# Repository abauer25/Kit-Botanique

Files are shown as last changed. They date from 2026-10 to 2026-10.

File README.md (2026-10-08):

# Kit Botanique V2

<p align="center">
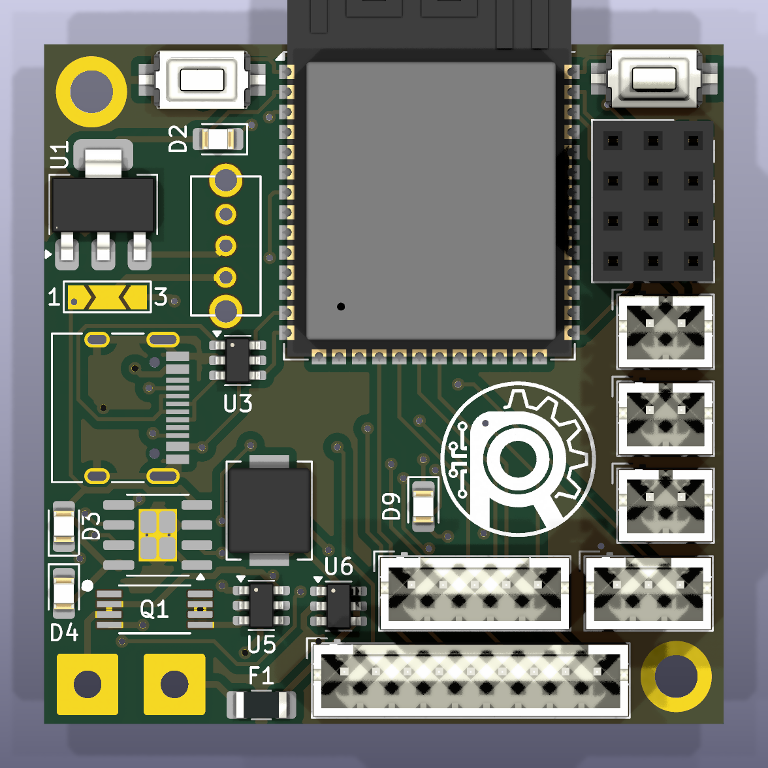
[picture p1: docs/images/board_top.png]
Top side of the board
  
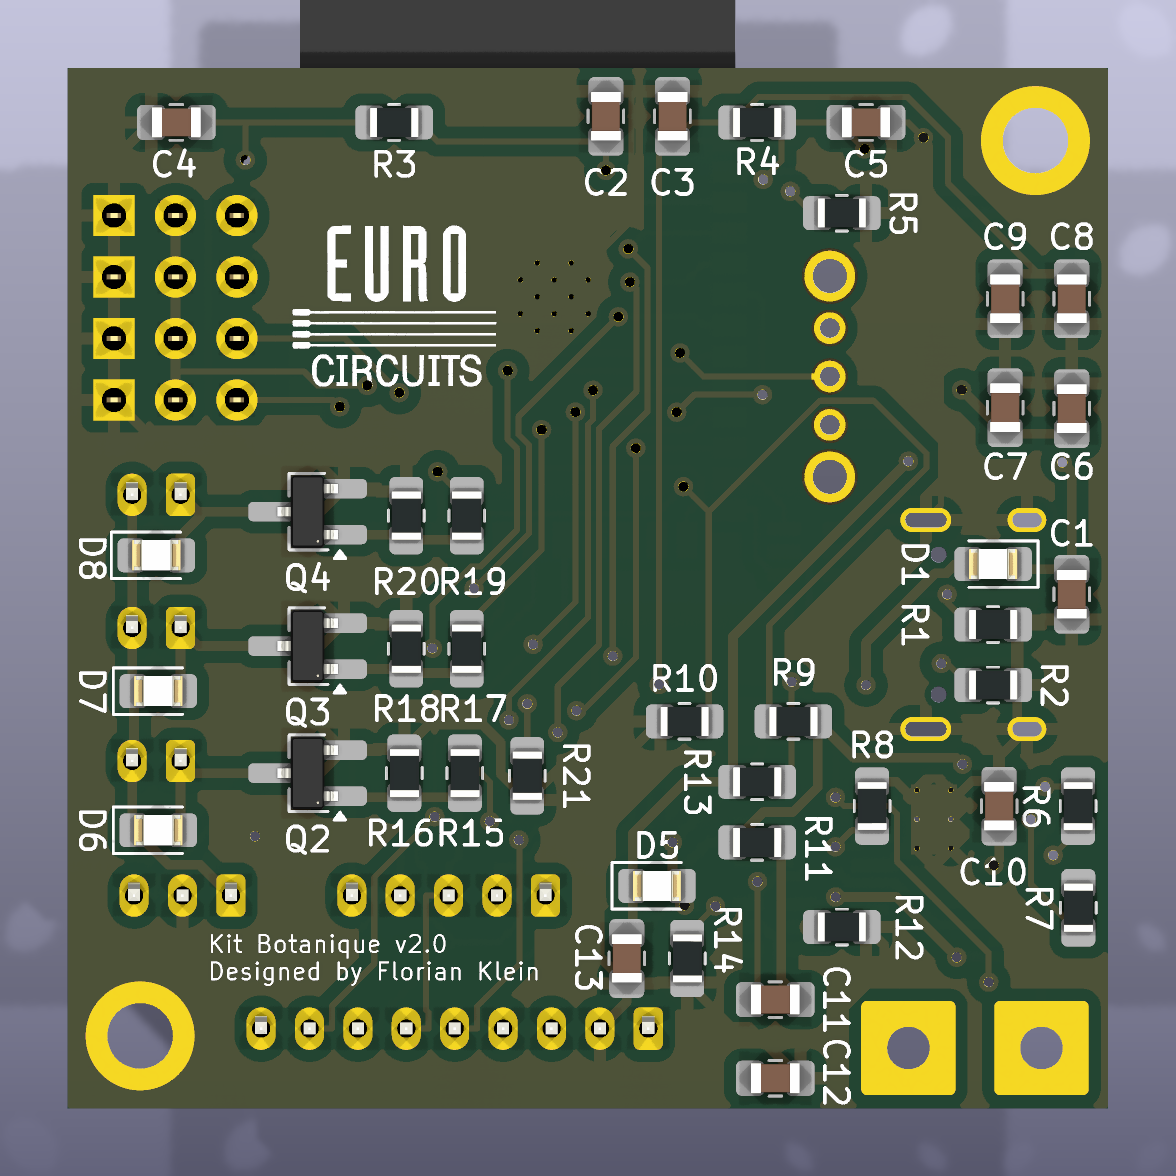
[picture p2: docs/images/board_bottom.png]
Bottom side of the board
  
</p>

The Kit Botanique is an automatic plant watering kit designed by [Robopoly](https://www.epfl.ch/campus/associations/robopoly/), the student makerspace of EPFL. It measures soil moisture and switches small pumps on when the plants need water.

Robopoly members buy the kit as separate parts and solder it themselves at the workshop, with help from the committee. It is an advanced kit: it uses small surface-mount components, so soldering experience is recommended but not required.

## Features

- ESP32-S3 module (WiFi and Bluetooth), programmed over USB-C with the Arduino IDE
- 3 pump outputs and 4 sensor inputs (soil moisture or water level)
- Powered over USB-C, or by a Li-ion battery with the optional battery extension
- Connectors for an LED strip and a touchscreen
- 43 × 43 mm board

The basic kit contains the board, one peristaltic pump and one soil moisture sensor.

## Repository contents

| Folder | Content |
|---|---|
| [`docs/`](docs) | [Assembly guide](docs/assembly_guide_v2.pdf), [schematic](docs/schema_v2.pdf), images |
| [`firmware/tests/`](firmware/tests) | Test programs used during assembly |
| [`hardware/kicad/`](hardware/kicad) | KiCad 10 project (schematic, PCB, libraries) |
| [`hardware/fabrication/`](hardware/fabrication) | Gerber files and bill of materials |
| [`hardware/3d/`](hardware/3d) | 3D model of the assembled board (STEP) |
| [`archive/v1/`](archive/v1) | Code of the first version of the kit |

## Building the kit

Follow the [assembly guide](docs/assembly_guide_v2.pdf) (in French for now). It goes step by step, with a test after each stage. Do not move on until the test passes.

| Stage | Guide sections | Test |
|---|---|---|
| 1. Power supply and ESP32 module | 1 to 9 | The blue LED lights up |
| 2. Buttons and white LED | 10 and 11 | `01_blink` makes the white LED blink |
| 3. Pumps and sensors | 12 to 14 | `02_pump_sensor_test` reads the sensors and runs the pumps |
| 4. Battery extension (optional) | 15 to 18 | |
| 5. Screen and LED strip connectors (optional) | 19 | |

Two things to know before you start:

- **Both sides of the board are used.** All resistors, capacitors, the Schottky diodes and the pump transistors go on the **bottom** side. The chips, LEDs, buttons and connectors go on the **top** side. Check the pictures above.
- **The 3-pad solder jumper (marked 1 and 3) selects the power source.** Bridge pads 1 and 2 for USB power (basic kit). Bridge pads 2 and 3 for battery power (battery extension). Never bridge all three pads.

## Programming

1. Install the [Arduino IDE](https://www.arduino.cc/en/software), then the **esp32 by Espressif Systems** package from the Boards Manager.
2. In the **Tools** menu, use these settings:

   | Setting | Value |
   |---|---|
   | Board | ESP32S3 Dev Module |
   | USB CDC On Boot | **Enabled** (otherwise the Serial Monitor stays empty) |
   | USB Mode | Hardware CDC and JTAG |
   | Upload Mode | USB-OTG CDC (TinyUSB) |
   | Flash Size | 4MB (32Mb) |
   | Partition Scheme | Default 4MB with spiffs |
   | PSRAM | Disabled |

3. Put the board in download mode: hold **BOOT** (top right button), press and release **RESET** (top left button), then release BOOT.
4. Upload the sketch. Then switch the board off and on again to start it.

The test programs in [`firmware/tests/`](firmware/tests):

| Sketch | What it does |
|---|---|
| [`01_blink`](firmware/tests/01_blink/01_blink.ino) | Blinks the white LED once per second |
| [`02_pump_sensor_test`](firmware/tests/02_pump_sensor_test/02_pump_sensor_test.ino) | Prints the 4 sensor values on the Serial Monitor (115200 baud), then runs the 3 pumps for 3 seconds |

> **Careful:** the white LED and pump 1 use the same pin. `01_blink` also runs pump 1 if one is plugged in.

The watering program itself is not written yet.

## Pinout

| GPIO | Function |
|---|---|
| 1, 2, 3, 4 | Sensor inputs C1 to C4 |
| 17, 18, 21 | Pumps 1 to 3 (pump 1 shares GPIO 17 with the white LED) |
| 15 | LED strip data |
| 14 | Battery voltage divided by 2 |
| 5, 6, 7, 10 | Screen: RST, DC, backlight, CS |
| 8, 16 | Touchscreen: CS, IRQ |
| 11, 12, 13 | SPI shared by screen and touchscreen: MOSI, SCLK, MISO |
| 0 | BOOT button |

Sensors are powered with 5 V, but their signal goes straight to the ESP32 and must stay below 3.3 V.

The full wiring is in the [schematic](docs/schema_v2.pdf).

## Hardware files

The KiCad project is in [`hardware/kicad/`](hardware/kicad). Open `kit_botanique_v2.kicad_pro` with KiCad 10 or later. The board is manufactured by Eurocircuits from [`gerber_v2.zip`](hardware/fabrication/gerber_v2.zip), the files that were sent for the current boards.

## First version

The first Kit Botanique used an ESP32 development board with 6 pumps and 6 sensors. Its code is kept in [`archive/v1/`](archive/v1/Sensors_Pumps_Test/Sensors_Pumps_Test.ino).

## Links

- [Kit Botanique V2 page](https://www.epfl.ch/campus/associations/robopoly/kits/kit-botanique-v2/)
- [Robopoly](https://www.epfl.ch/campus/associations/robopoly/), workshop BM 9139, EPFL
- Contact: [robopoly@epfl.ch](mailto:robopoly@epfl.ch)

## License

This project is published by Robopoly under the [Creative Commons Attribution-NonCommercial-ShareAlike 4.0](LICENSE.txt) license.

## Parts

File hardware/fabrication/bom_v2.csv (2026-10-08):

Reference | Qty | Value | DNP | Exclude from BOM | Exclude from Board | Footprint | Datasheet | LCSC
C1,C2,C6,C8,C10 | 5 | 10uF |  |  |  | Capacitor_SMD:C_0805_2012Metric_Pad1.18x1.45mm_HandSolder | ~
C3,C4,C5,C7,C9,C11 | 6 | 100nF |  |  |  | Capacitor_SMD:C_0805_2012Metric_Pad1.18x1.45mm_HandSolder | ~
C12,C13 | 2 | 22uF |  |  |  | Capacitor_SMD:C_0805_2012Metric_Pad1.18x1.45mm_HandSolder | ~
D1,D5,D6,D7,D8 | 5 | 1N5819HW-7-F |  |  |  | LED_SMD:LED_0805_2012Metric_Pad1.15x1.40mm_HandSolder | https://datasheet.lcsc.com/lcsc/2204281430_Guangdong-Hottech-1N5819WS_C191023.pdf
D2,D3,D4,D9 | 4 | LED |  |  |  | LED_SMD:LED_0805_2012Metric_Pad1.15x1.40mm_HandSolder | ~
F1 | 1 | Polyfuse |  |  |  | Fuse:Fuse_1206_3216Metric_Pad1.42x1.75mm_HandSolder | ~
J1 | 1 | USB_C_Receptacle_USB2.0_16P |  |  |  | Connector_USB:USB_C_Receptacle_HRO_TYPE-C-31-M-12 | https://www.usb.org/sites/default/files/documents/usb_type-c.zip | C165948
J2 | 1 | Screen |  |  |  | Connector_JST:JST_PH_B9B-PH-K_1x09_P2.00mm_Vertical | ~
J3 | 1 | C1 |  |  |  | Connector_PinSocket_2.54mm:PinSocket_1x03_P2.54mm_Vertical | ~
J4 | 1 | touch_screen |  |  |  | Connector_JST:JST_PH_B5B-PH-K_1x05_P2.00mm_Vertical | ~
J5 | 1 | connecteur_LED |  |  |  | Connector_JST:JST_PH_B3B-PH-K_1x03_P2.00mm_Vertical | ~
J7 | 1 | Bat+ |  |  |  | Connector_Wire:SolderWire-1sqmm_1x01_D1.4mm_OD3.9mm | ~
J8 | 1 | Bat- |  |  |  | Connector_Wire:SolderWire-1sqmm_1x01_D1.4mm_OD3.9mm | ~
J11 | 1 | Pump1 |  |  |  | Connector_JST:JST_PH_B2B-PH-K_1x02_P2.00mm_Vertical | ~
J12 | 1 | Pump2 |  |  |  | Connector_JST:JST_PH_B2B-PH-K_1x02_P2.00mm_Vertical | ~
J13 | 1 | Pump3 |  |  |  | Connector_JST:JST_PH_B2B-PH-K_1x02_P2.00mm_Vertical | ~
J14 | 1 | C2 |  |  |  | Connector_PinSocket_2.54mm:PinSocket_1x03_P2.54mm_Vertical | ~
J15 | 1 | C3 |  |  |  | Connector_PinSocket_2.54mm:PinSocket_1x03_P2.54mm_Vertical | ~
J16 | 1 | C4 |  |  |  | Connector_PinSocket_2.54mm:PinSocket_1x03_P2.54mm_Vertical | ~
L1 | 1 | 4.7uH |  |  |  | Library:inductor_48100SC | ~ | C5123183
Q1 | 1 | FS8205A |  |  |  | FS8205A:SOP65P640X120-8N
Q2,Q3,Q4 | 3 | AO3400A |  |  |  | Package_TO_SOT_SMD:SOT-23_Handsoldering | http://www.aosmd.com/pdfs/datasheet/AO3400A.pdf
R1,R2 | 2 | 5k1 |  |  |  | Resistor_SMD:R_0805_2012Metric_Pad1.20x1.40mm_HandSolder | ~
R3,R4,R9,R10,R16,R18,R20 | 7 | 10k |  |  |  | Resistor_SMD:R_0805_2012Metric_Pad1.20x1.40mm_HandSolder | ~
R5,R6,R7,R12,R21 | 5 | 1k |  |  |  | Resistor_SMD:R_0805_2012Metric_Pad1.20x1.40mm_HandSolder | ~
R8 | 1 | 1k2 |  |  |  | Resistor_SMD:R_0805_2012Metric_Pad1.20x1.40mm_HandSolder | ~
R11,R15,R17,R19 | 4 | 100 |  |  |  | Resistor_SMD:R_0805_2012Metric_Pad1.20x1.40mm_HandSolder | ~
R13 | 1 | 22k |  |  |  | Resistor_SMD:R_0805_2012Metric_Pad1.20x1.40mm_HandSolder | ~
R14 | 1 | 3k |  |  |  | Resistor_SMD:R_0805_2012Metric_Pad1.20x1.40mm_HandSolder | ~
SW1,SW2 | 2 | SW_MEC_5G |  |  |  | Library:bouton_smd_kit_botanique | http://www.apem.com/int/index.php?controller=attachment&id_attachment=488
U1 | 1 | AMS1117-3.3 |  |  |  | Package_TO_SOT_SMD:SOT-223-3_TabPin2 | http://www.advanced-monolithic.com/pdf/ds1117.pdf
U2 | 1 | ESP32-S3-WROOM-1 |  |  |  | PCM_Espressif:ESP32-S3-WROOM-1_homemade | https://www.espressif.com/sites/default/files/documentation/esp32-s3-wroom-1_wroom-1u_datasheet_en.pdf | C2913199
U3 | 1 | USBLC6-2SC6 |  |  |  | Package_TO_SOT_SMD:SOT-23-6 | https://www.st.com/resource/en/datasheet/usblc6-2.pdf
U4 | 1 | TP4056-42-ESOP8 |  |  |  | Package_SO:SOIC-8-1EP_3.9x4.9mm_P1.27mm_EP2.41x3.3mm_ThermalVias | https://www.lcsc.com/datasheet/lcsc_datasheet_2410121619_TOPPOWER-Nanjing-Extension-Microelectronics-TP4056-42-ESOP8_C16581.pdf | C16581
U5 | 1 | DW01A |  |  |  | Package_TO_SOT_SMD:SOT-23-6 | https://hmsemi.com/downfile/DW01A.PDF | C436931
U6 | 1 | MT3608 |  |  |  | Package_TO_SOT_SMD:SOT-23-6 | https://www.olimex.com/Products/Breadboarding/BB-PWR-3608/resources/MT3608.pdf | C84817
U7 | 1 | SK12D07VG4 |  |  |  | SK12D07VG4:SK12D07VG4

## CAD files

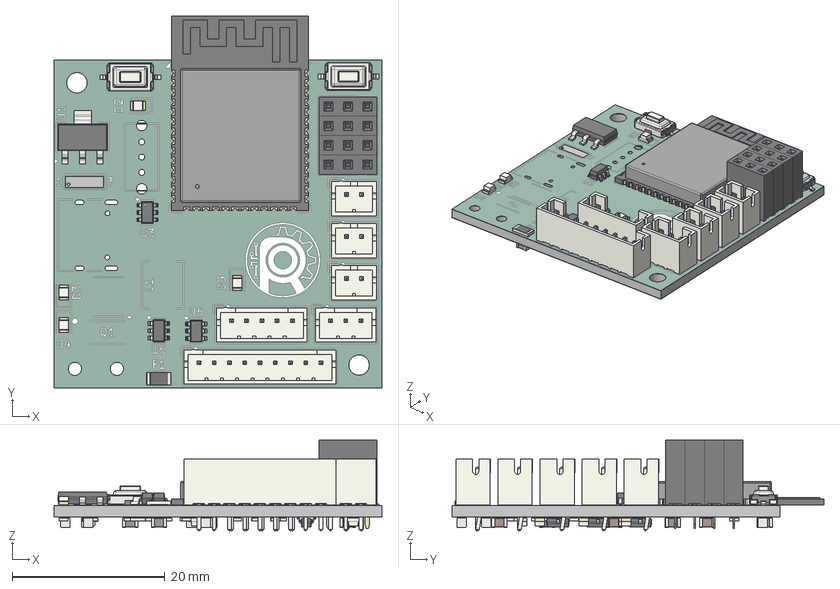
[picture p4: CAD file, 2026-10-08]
hardware/3d/kit_botanique_v2.step
43.0 x 48.8 x 11.9 mm
Fuse_1206_3216Metric
PinSocket_1x03_P2.54mm_Vertical x 4
SOT-23-6 x 3
SOT-223
JST_PH_B5B-PH-K_1x05_P2.00mm_Vertical
JST_PH_B2B-PH-K_1x02_P2.00mm_Vertical x 3
LED_0805_2012Metric x 9
ESP32-S3-WROOM-1
SW_Tactile_SPST_NO_Straight_CK_PTS636Sx25SMTRLFS x 2
JST_PH_B3B-PH-K_1x03_P2.00mm_Vertical
JST_PH_B9B-PH-K_1x09_P2.00mm_Vertical
C_0805_2012Metric x 13
R_0805_2012Metric x 21
SOT-23 x 3
new version_silkscreen
new version_soldermask
new version_PCB

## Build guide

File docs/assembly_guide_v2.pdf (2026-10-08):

# Kit Botanique

## Marche à suivre — Assemblage & Tests

## 🔧 Outils nécessaires

- Fer à souder réglé à 350°C
- Pincettes de précision
- Étain (fil de soudure)
- Flux (pour certaines étapes SMD)
- Microscope ou loupe pour contrôler les soudures

💡 Nettoyer la panne du fer régulièrement avec de la laine d'acier pour garantir de bonnes soudures.

## 1 Port USB-C

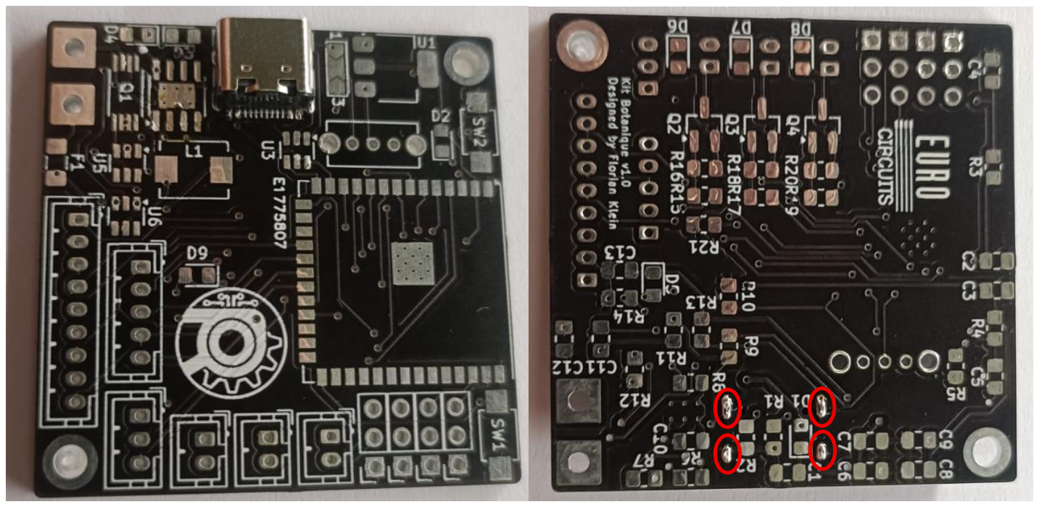
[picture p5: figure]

Pins traversants
1. Positionner le connecteur USB-C sur le PCB en s'assurant qu'il est bien plaqué contre le PCB.

2. Souder les 4 pins traversants en appliquant une quantité suffisante d'étain.
3. Vérifier visuellement que chaque joint est brillant et bien formé.

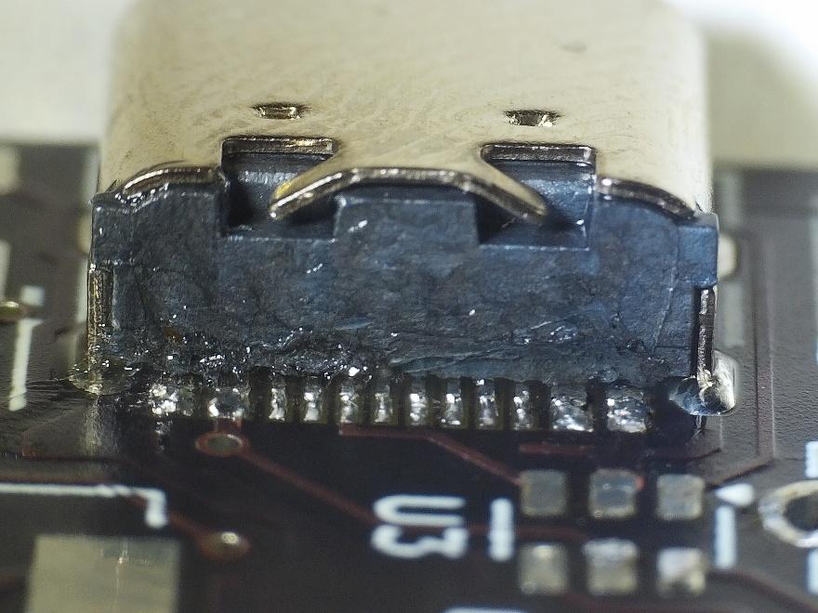
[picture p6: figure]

Pins SMD
4. Appliquer une fine couche de flux sur les pins SMD.
5. Déposer une petite quantité d'étain sur la panne du fer.
6. Faire glisser la panne sur tous les pins en un seul mouvement continu.
7. Contrôler l'absence de bridges sous microscope.

⚠️ S'assurer qu'aucun pin SMD n'est bridgé avec son voisin avant de continuer.

## 2 Chip de protection USB

Référence | Composant
U3 | USBLC6

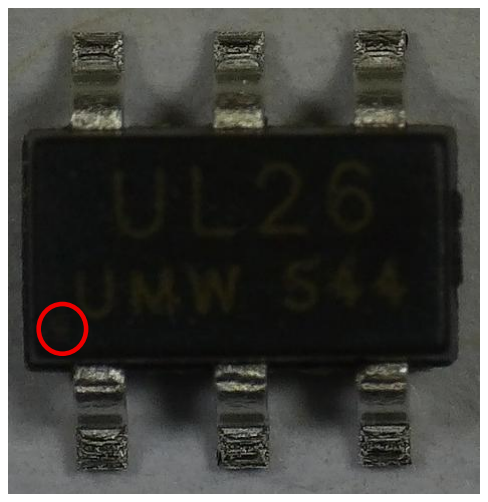
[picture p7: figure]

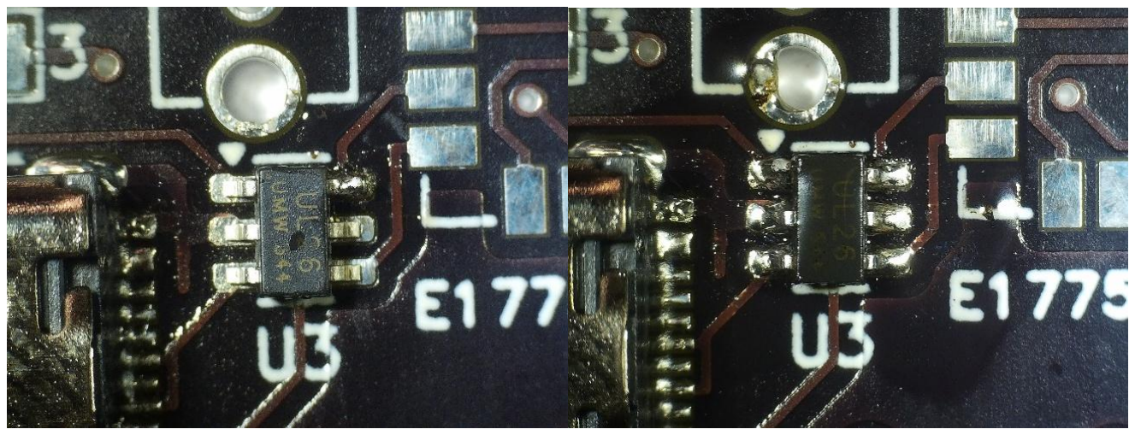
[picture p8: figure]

8. Repérer l'orientation du composant : le point sur la chip doit être aligné avec la flèche sur le silkscreen.
9. Souder un premier pin pour fixer le composant.
10. Vérifier l'alignement avant de continuer.
11. Souder tous les pins restants.

## 3 Régulateur de tension (5V → 3.3V)

Référence | Composant
U1 | AMS1117-3.3
D2 | LED bleue

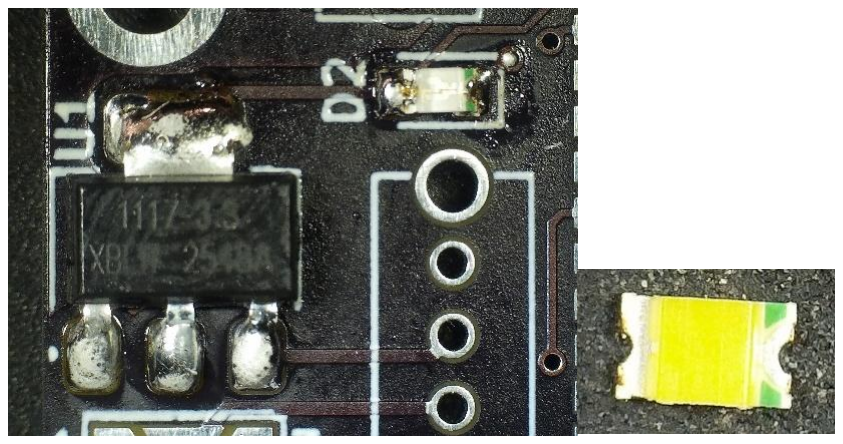
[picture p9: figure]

12. Souder le régulateur de tension AMS1117-3.3.
13. Souder la LED bleue D2 en respectant le sens : la partie verte de la LED et l'indication sur le silkscreen indiquent la cathode (borne négative).

⚠️ Le sens de la LED est critique : une LED inversée ne s'allumera pas et peut indiquer un problème d'alimentation.

## 4 Module ESP32-S3

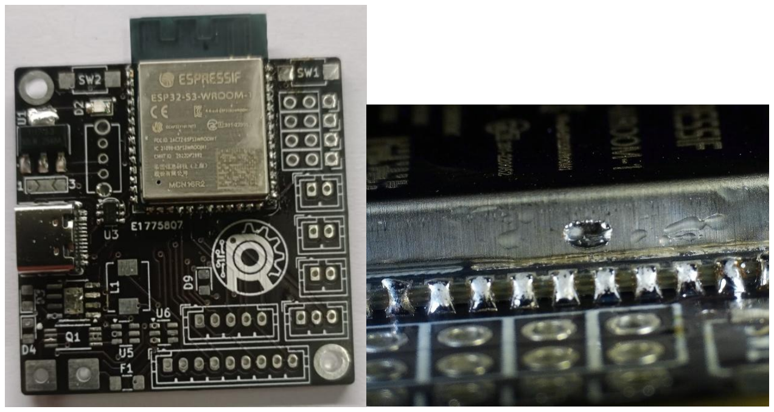
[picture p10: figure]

14. Positionner le module ESP32-S3 en alignant soigneusement tous les pins avec les pads du PCB.
15. Souder un coin pour verrouiller la position.
16. Vérifier l'alignement de l'ensemble des pins.
17. Souder tous les pins restants.
18. Inspecter chaque soudure au microscope pour confirmer le contact entre chaque pin et son pad.

💡 Commencer par souder les angles opposés pour maintenir le module bien centré.

## 5 Circuit USB-C

Référence | Composant
D1 | 1N5819
C1 | 10µF
R1, R2 | 5.1k

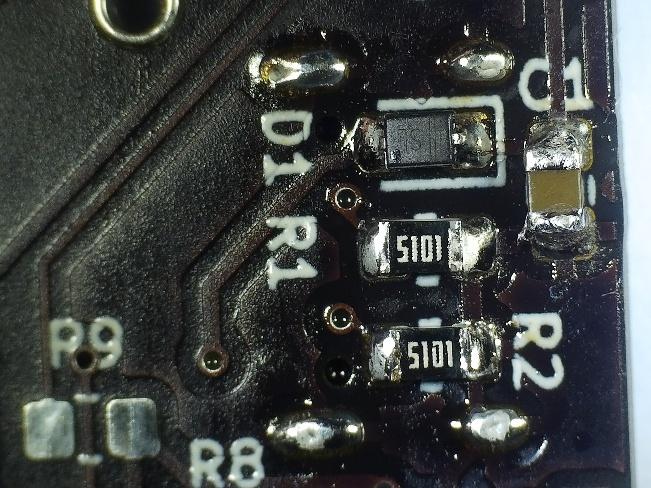
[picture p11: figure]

- D1 : la barre de la diode doit être orientée vers la marque sur le silkscreen.

⚠️ L'orientation de D1 est critique pour le bon fonctionnement de la protection USB.

## 6 Circuit régulateur de tension

Référence | Composant
C7, C9 | 100nF
C6, C8 | 10µF
R5 | 1k

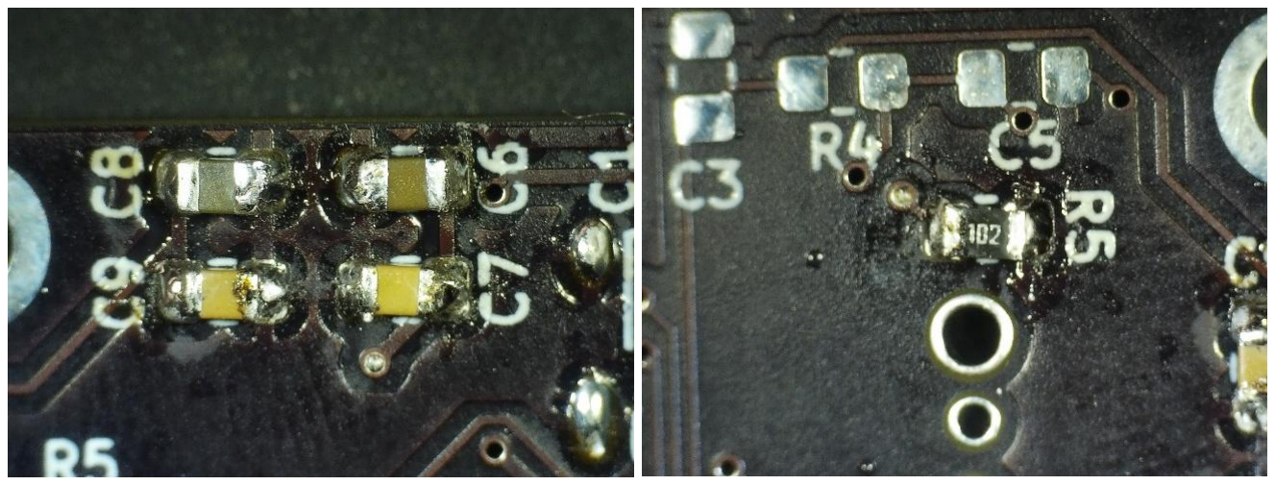
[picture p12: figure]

Souder tous les composants passifs. Les condensateurs et résistances n'ont pas de polarité, seul le sens n'est pas critique.

## 7 Circuit ESP32-S3 (composants passifs)

Référence | Composant
C3, C4, C5 | 100nF
C2 | 10µF
R3, R4 | 10k

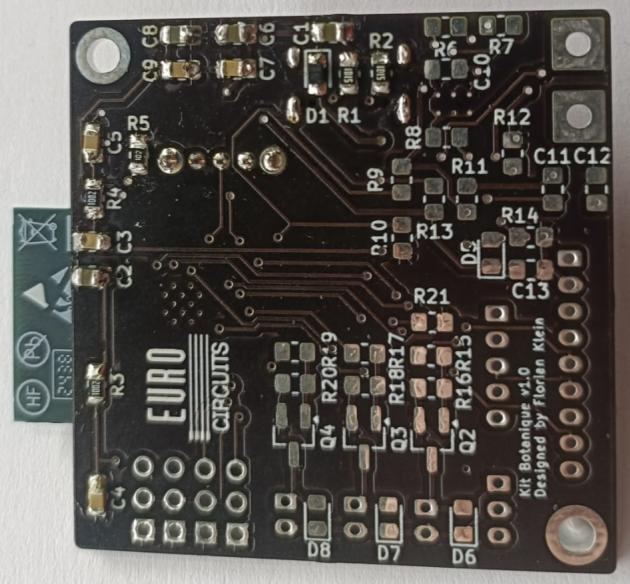
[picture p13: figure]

## 8 Interrupteur et solder jumper

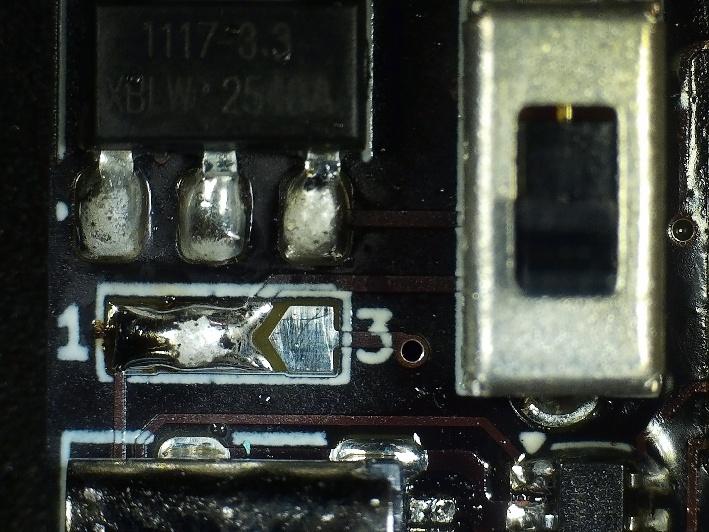
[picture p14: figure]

19. Souder l'interrupteur sur le PCB.
20. Souder le solder jumper pour relier les pads 1 et 2 avec de l'étain.

💡 Le solder jumper connecte le 5V USB au reste du circuit. Sans cette connexion, le PCB ne sera pas alimenté via USB.

## 9 Test alimentation ⚡

⚠️ Inspecter toutes les soudures avant de brancher quoi que ce soit. Vérifier l'absence de bridges sur tous les composants.

✅ PROCÉDURE DE TEST

21. Brancher le PCB à une alimentation 5V via le câble USB-C.
22. Vérifier que la LED bleue s'allume immédiatement.

23. Si la LED ne s'allume pas : vérifier le sens de D1 et D2, les soudures de U3 (USBLC6), et l'état du solder jumper.

## 10 LED blanche et boutons ESP32

Référence | Composant
D9 | LED blanche
R21 | 1k
SW1 | Bouton BOOT
SW2 | Bouton RESET

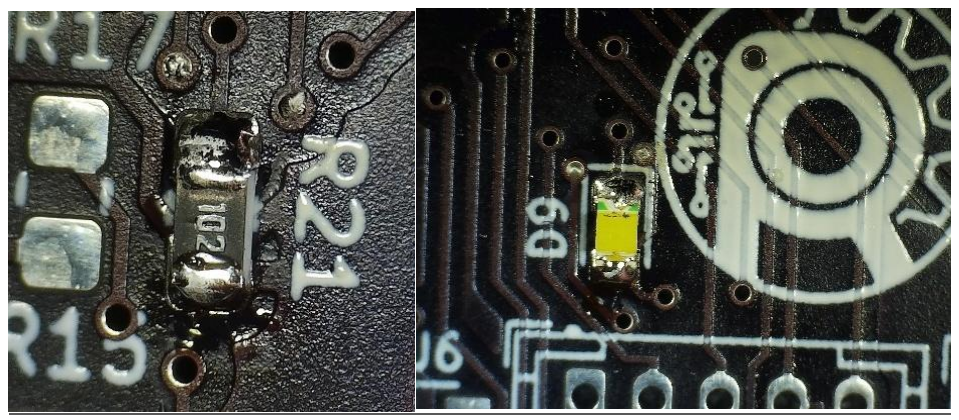
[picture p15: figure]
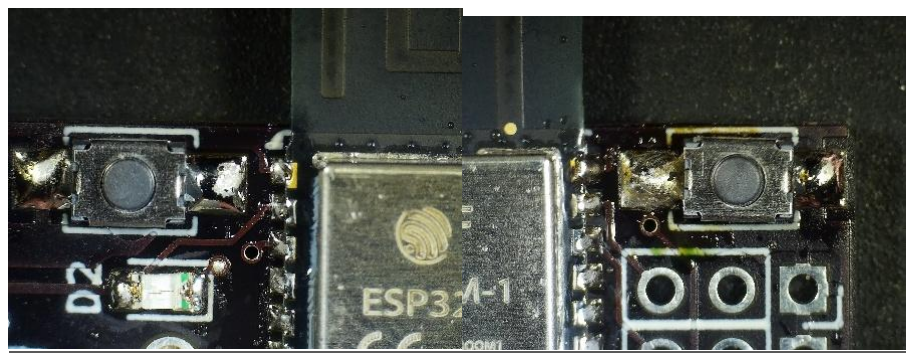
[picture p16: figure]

24. Souder D9 (LED blanche) et R21 (1k) en respectant le sens de la LED.
25. Souder le bouton SW1 (BOOT) à gauche.
26. Souder le bouton SW2 (RESET) à droite.

## 11 Test ESP32

Mise en mode téléchargement
27. Brancher l'ESP32 à l'ordinateur via USB.
28. Vérifier que la LED bleue est bien allumée.
29. Maintenir SW1 (BOOT) appuyé.

30. Appuyer brièvement sur SW2 (RESET) puis le relâcher.
31. Relâcher SW1 (BOOT). L'ESP32 est maintenant en mode téléchargement.
32. Dans le Gestionnaire de périphériques Windows, vérifier qu'un port COM est détecté et stable.

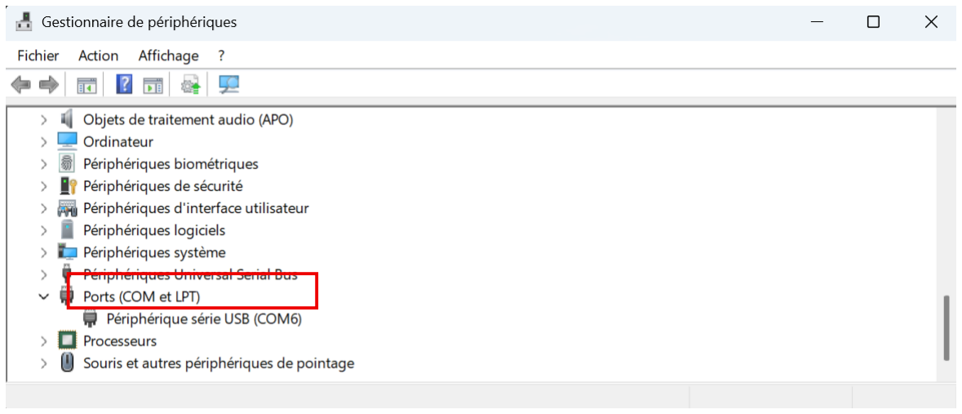
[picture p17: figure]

Configuration Arduino IDE
33. Dans le Board Manager, installer "esp32 by Espressif Systems".

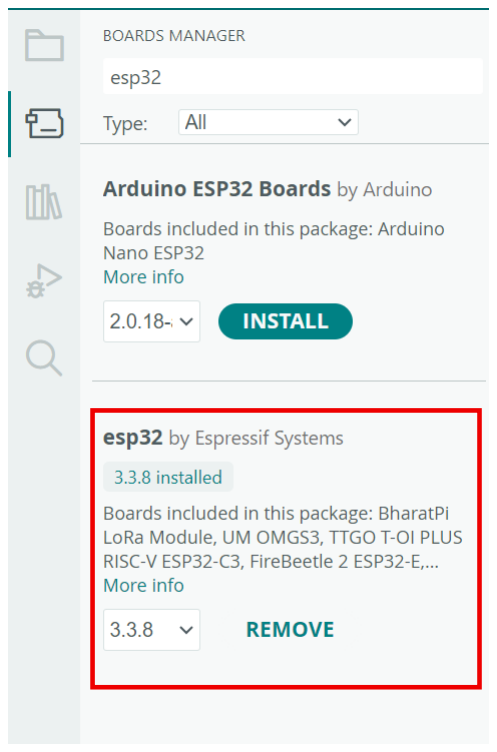
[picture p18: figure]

34. Sélectionner le bon port COM et la board "ESP32S3 Dev Module".

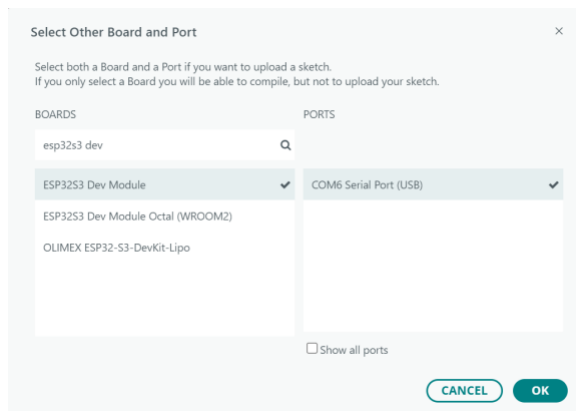
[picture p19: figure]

35. Vérifier que les paramètres correspondent aux valeurs indiquées dans la documentation.

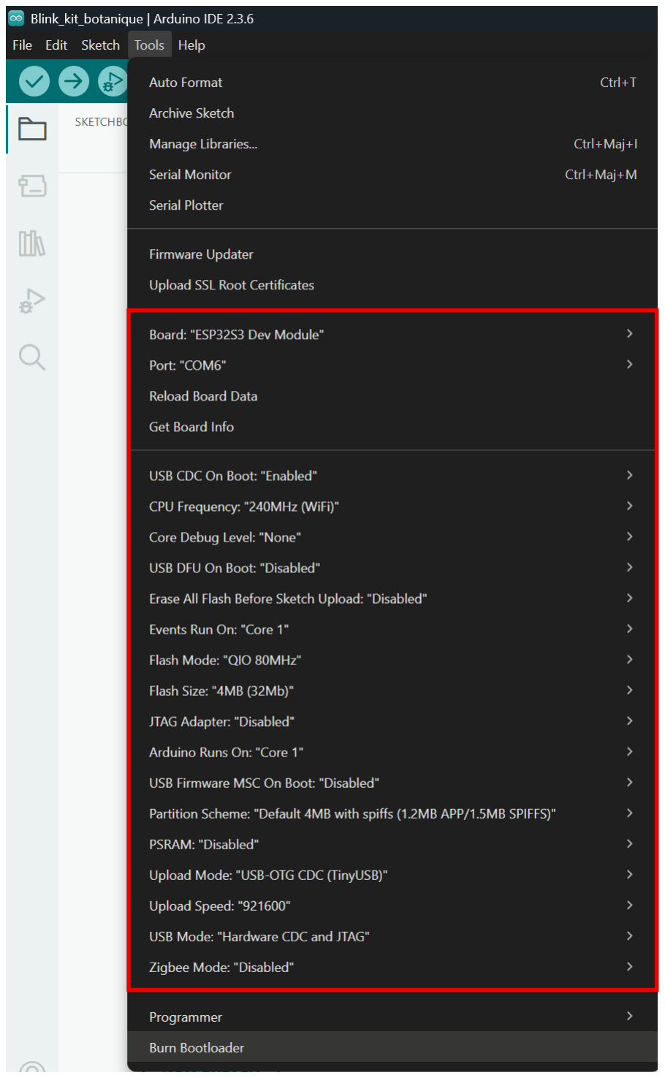
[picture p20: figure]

36. Uploader le code Blink.
37. Éteindre et rallumer la board. Vérifier que la LED blanche clignote.

## 12 Circuits de contrôle des pompes

Référence | Composant
Q2, Q3, Q4 | AO3400 (MOSFET N)
R15, R17, R19 | 100Ω
R16, R18, R20 | 10k
D6, D7, D8 | 1N5819

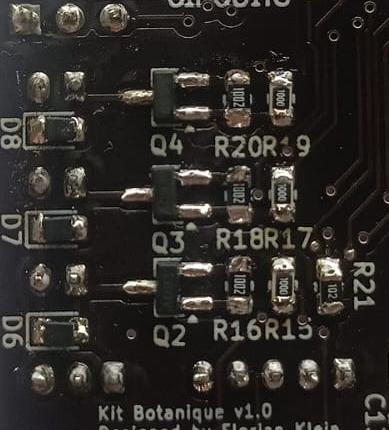
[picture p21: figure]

38. Souder les résistances R15–R20.
39. Souder les MOSFET Q2, Q3, Q4 en respectant l'orientation.
40. Souder les diodes D6, D7, D8 en respectant le sens (barre vers la marque silkscreen).

⚠️ Le sens des diodes D6/D7/D8 est critique : une diode inversée peut court-circuiter l'alimentation des pompes.

## 13 Connecteurs moteurs et capteurs

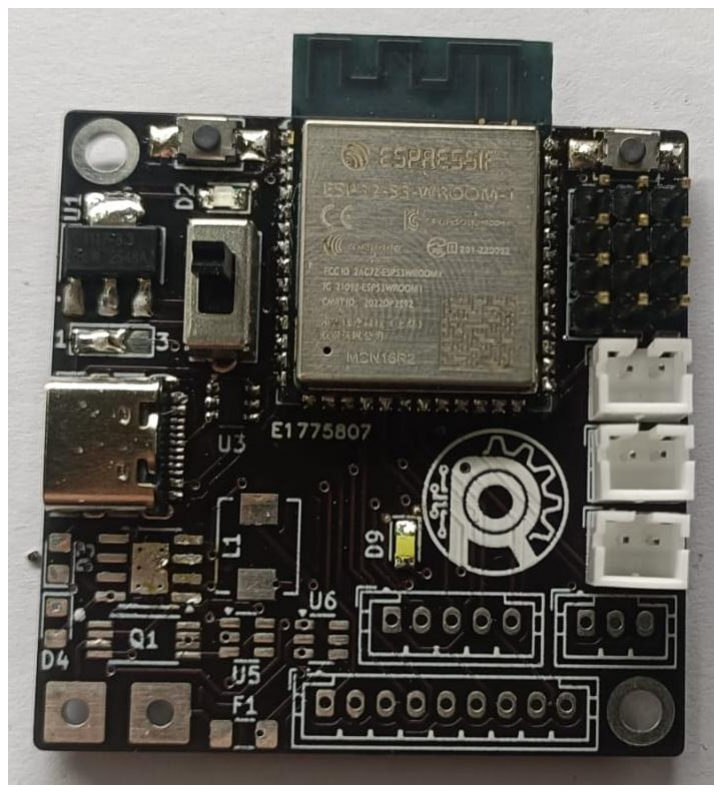
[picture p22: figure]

41. Souder les pin headers 3×4 pins pour les capteurs d'humidité en veillant à les maintenir bien perpendiculaires au PCB.
42. Souder les connecteurs JST-PH 2 pins pour les moteurs.

💡 Utiliser un support ou du scotch pour maintenir les connecteurs droits pendant la soudure.

## 14 Test pompes et capteurs

✅ PROCÉDURE DE TEST

43. Uploader le code test_pompes_capteurs.
44. Ouvrir le terminal série et vérifier que tous les capteurs sont détectés.
45. Vérifier que les valeurs des capteurs changent en fonction de l'environnement.
46. Brancher les pompes et vérifier qu'elles s'activent correctement.

## 15 BMS — TP4056

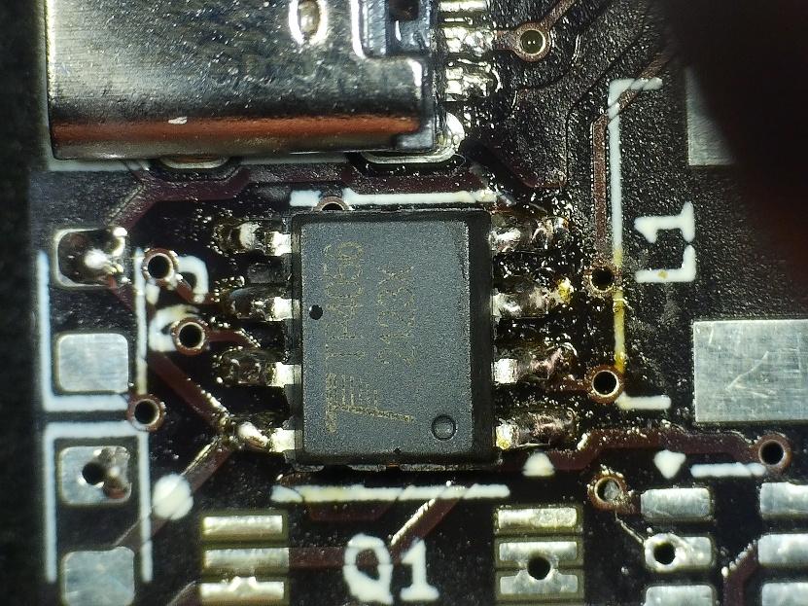
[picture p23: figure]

47. Souder la chip TP4056 en faisant bien attention à l'orientation (repère de broche 1).
Référence | Composant
D3 | LED verte
D4 | LED rouge
R6, R7 | 1k
R8 | 1.2k
C10 | 10µF

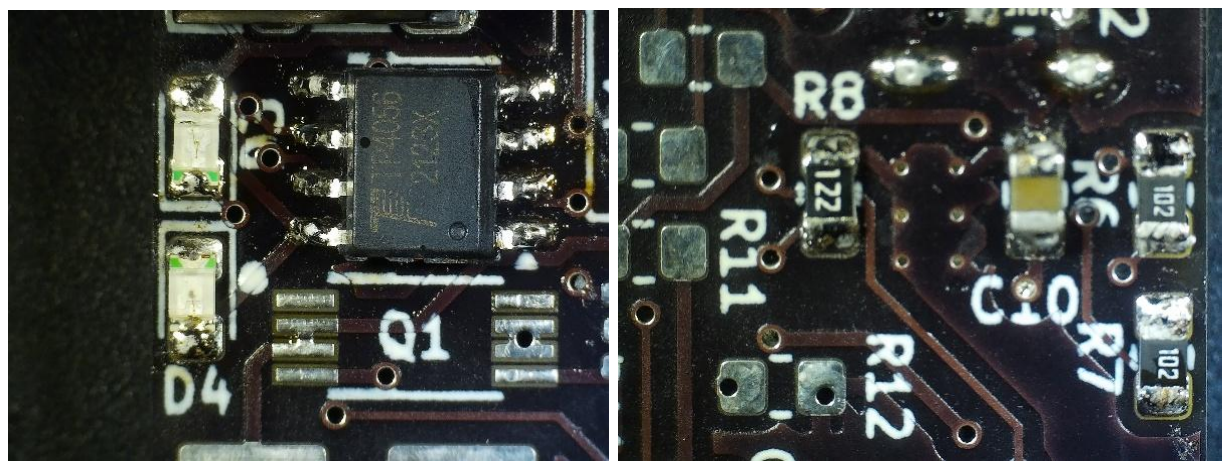
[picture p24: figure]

48. Souder tous les composants du circuit TP4056 en respectant le sens des LEDs.

✅ PROCÉDURE DE TEST

49. Souder le solder jumper sur les pads 2-3. Vérifier que le pad 1 n'est pas connecté au pad 2.
50. Brancher le câble USB à l'alimentation.
51. Vérifier que les LEDs verte et rouge s'allument.

## 16 FS8205

52. Appliquer du flux sur les pads de Q1.
53. Souder la chip FS8205 sur Q1.

💡 Si les pins 2-3 ou 6-7 sont connectés ensemble après soudure, ce n’est pas grave.

## 17 DW01A

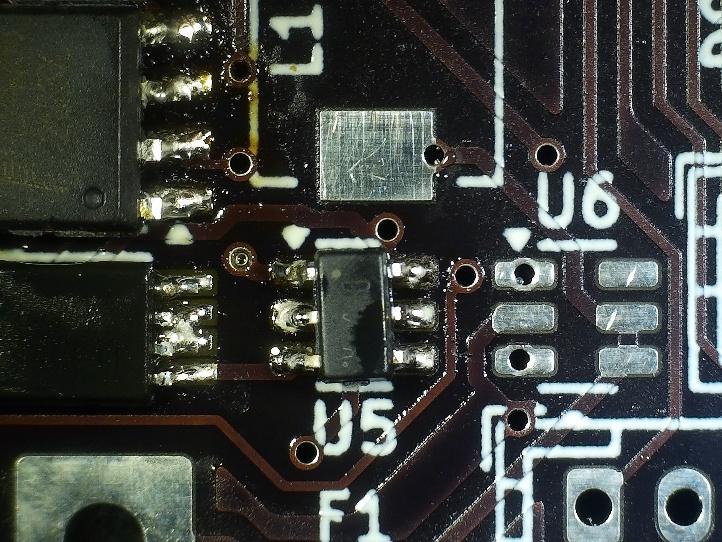
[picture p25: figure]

54. Souder DW01A sur U5.
Référence | Composant
F1 | Fusible PTC
R11 | 100Ω
R12 | 1k
C11 | 100nF

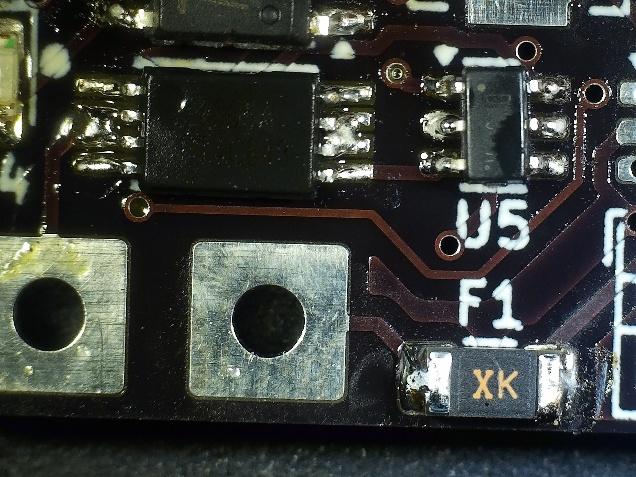
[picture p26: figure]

- Vérifier que le fusible PTC F1 est bien soudé avec de l'étain visible tout autour des pads.

## 18 Circuit MT3608 (boost converter)

Référence | Composant
U6 | MT3608
L1 | 4.7µH
R13 | 22k
R14 | 3k
R9, R10 | 10k
D5 | 1N5819
C12, C13 | 22µF

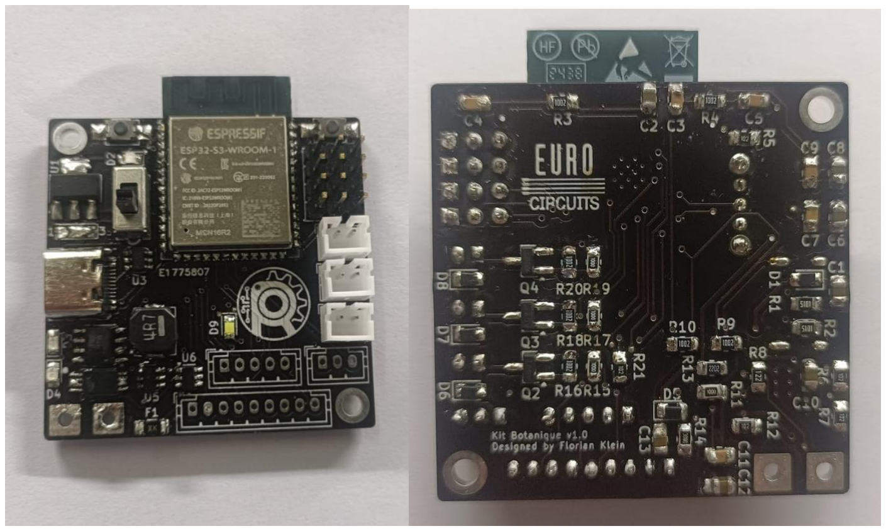
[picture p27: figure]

55. Souder U6 (MT3608) en respectant l'orientation.

56. Souder L1 (inductance 4.7µH).
57. Souder D5 en respectant le sens (barre vers la marque silkscreen).
58. Souder toutes les résistances et condensateurs.

⚠️ Le sens de D5 est critique pour le fonctionnement du boost converter.

## 19 Écran et bande de LED

Écran

59. Souder le connecteur JST 9 pins.
60. Souder le connecteur JST 5 pins.

Bande de LED
61. Souder le connecteur JST-PH 3 pins.

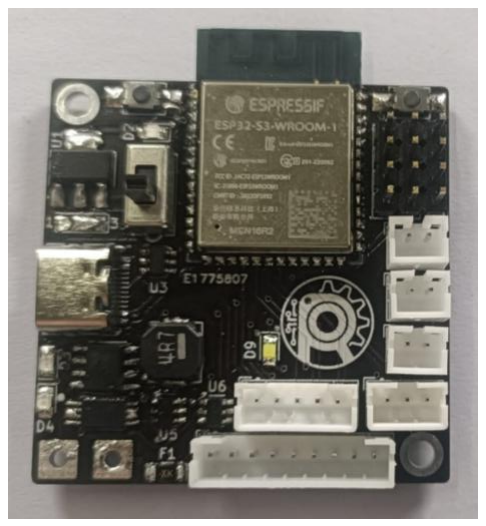
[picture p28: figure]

Assemblage terminé — Bon fonctionnement ! 🌱

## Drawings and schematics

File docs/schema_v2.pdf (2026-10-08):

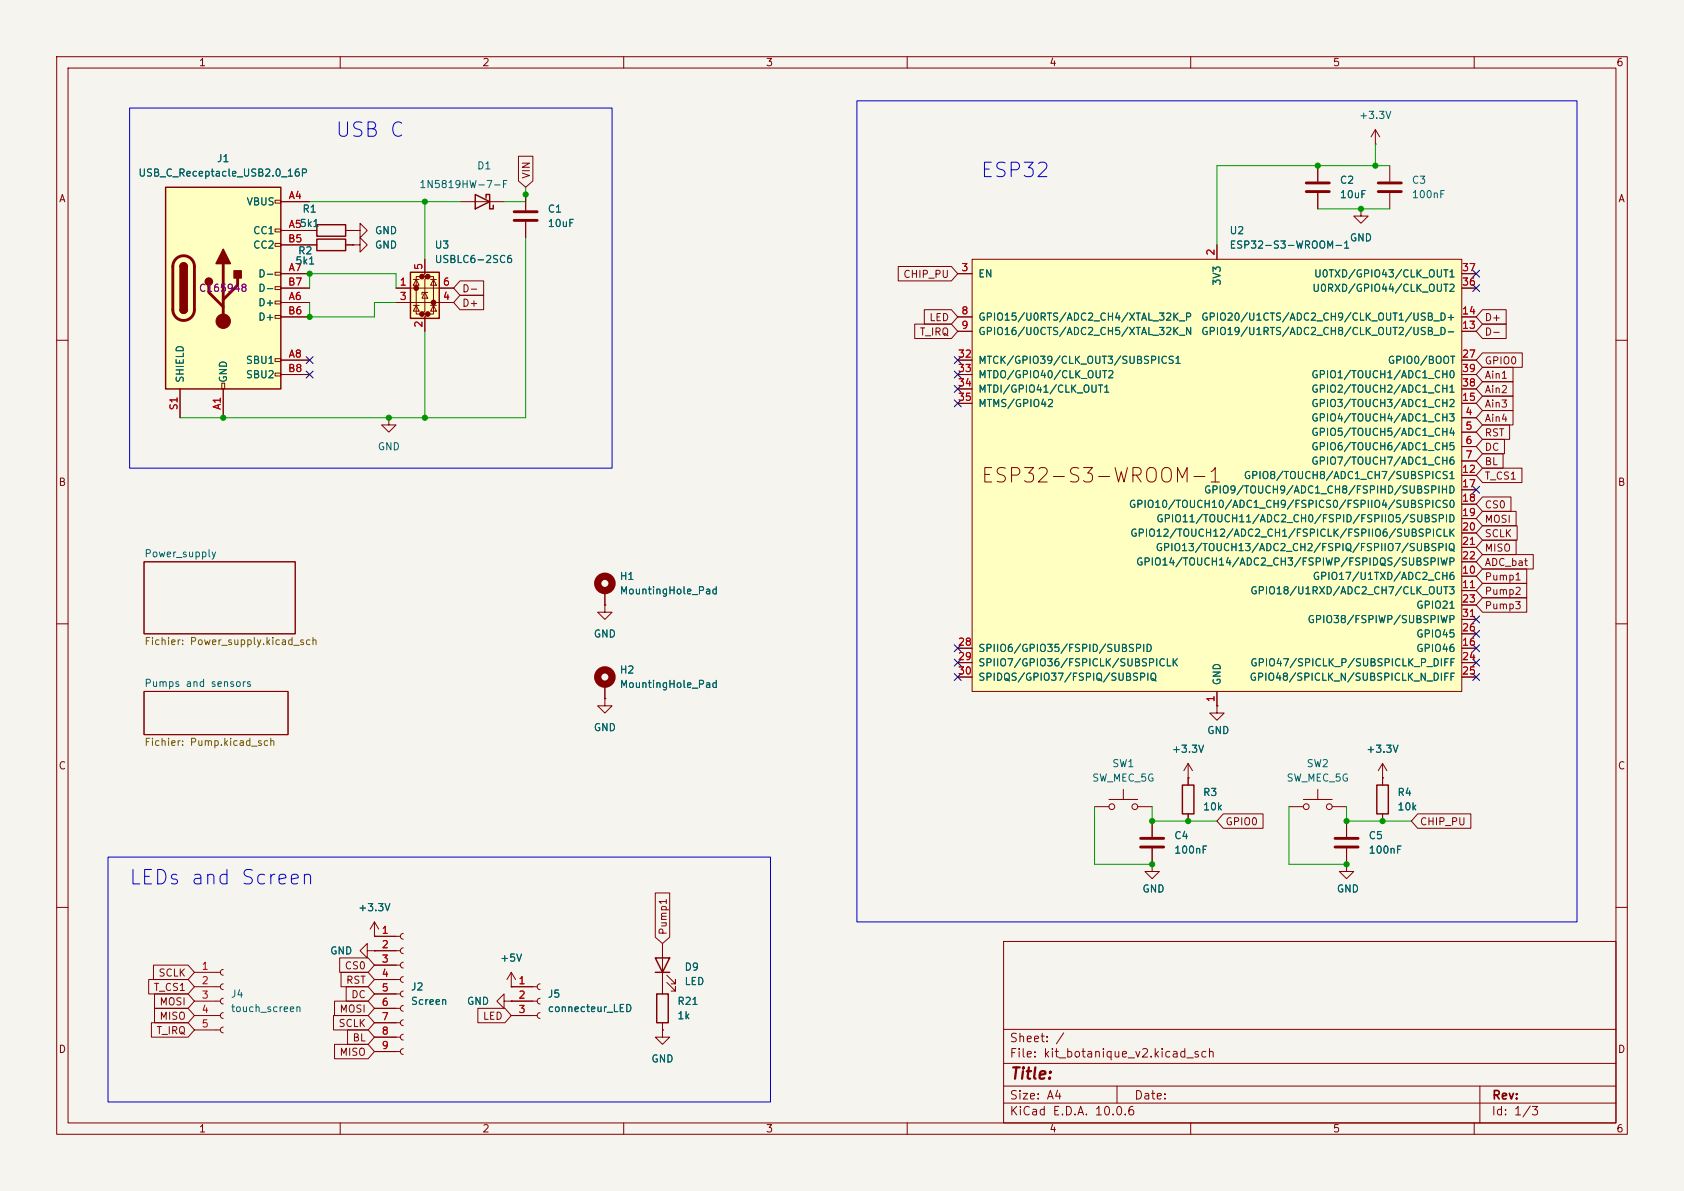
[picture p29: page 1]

LEDs and Screen

Size: A4 | Rev:
KiCad E.D.A. 10.0.6 | Id: 1/3

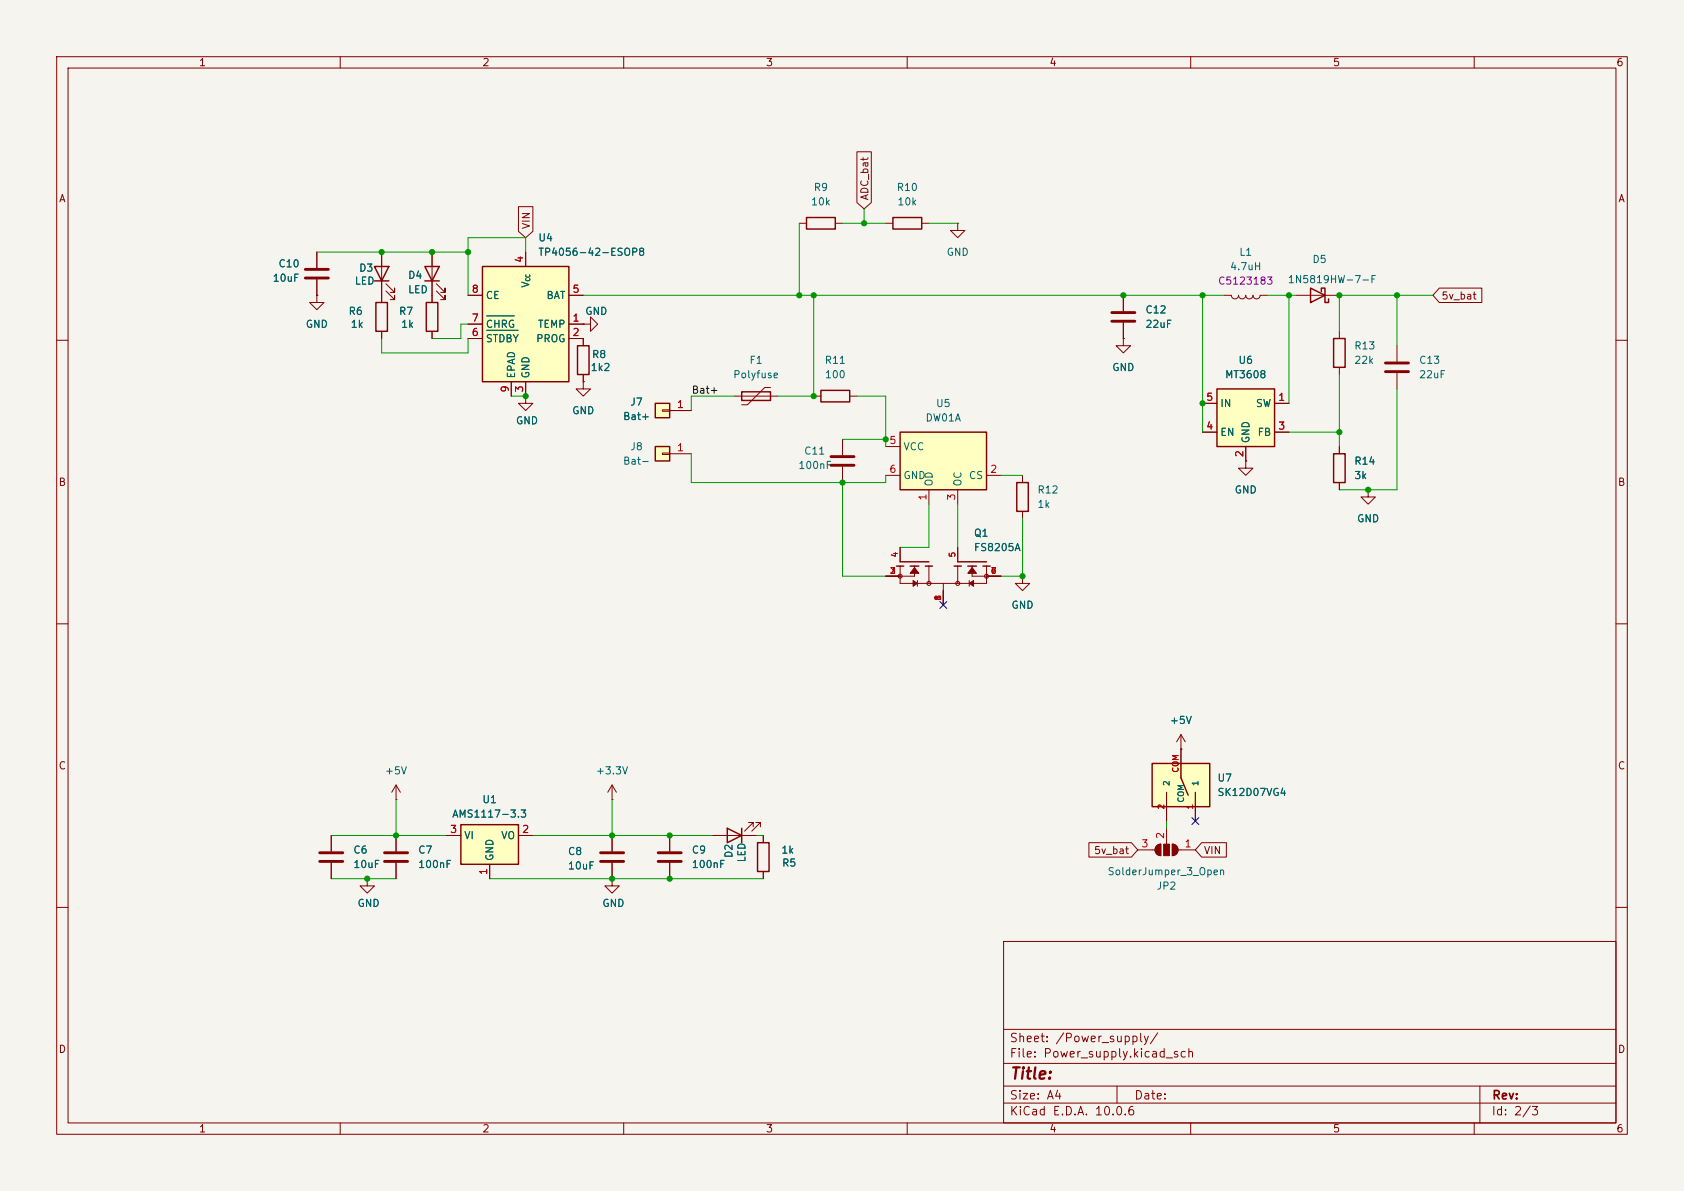
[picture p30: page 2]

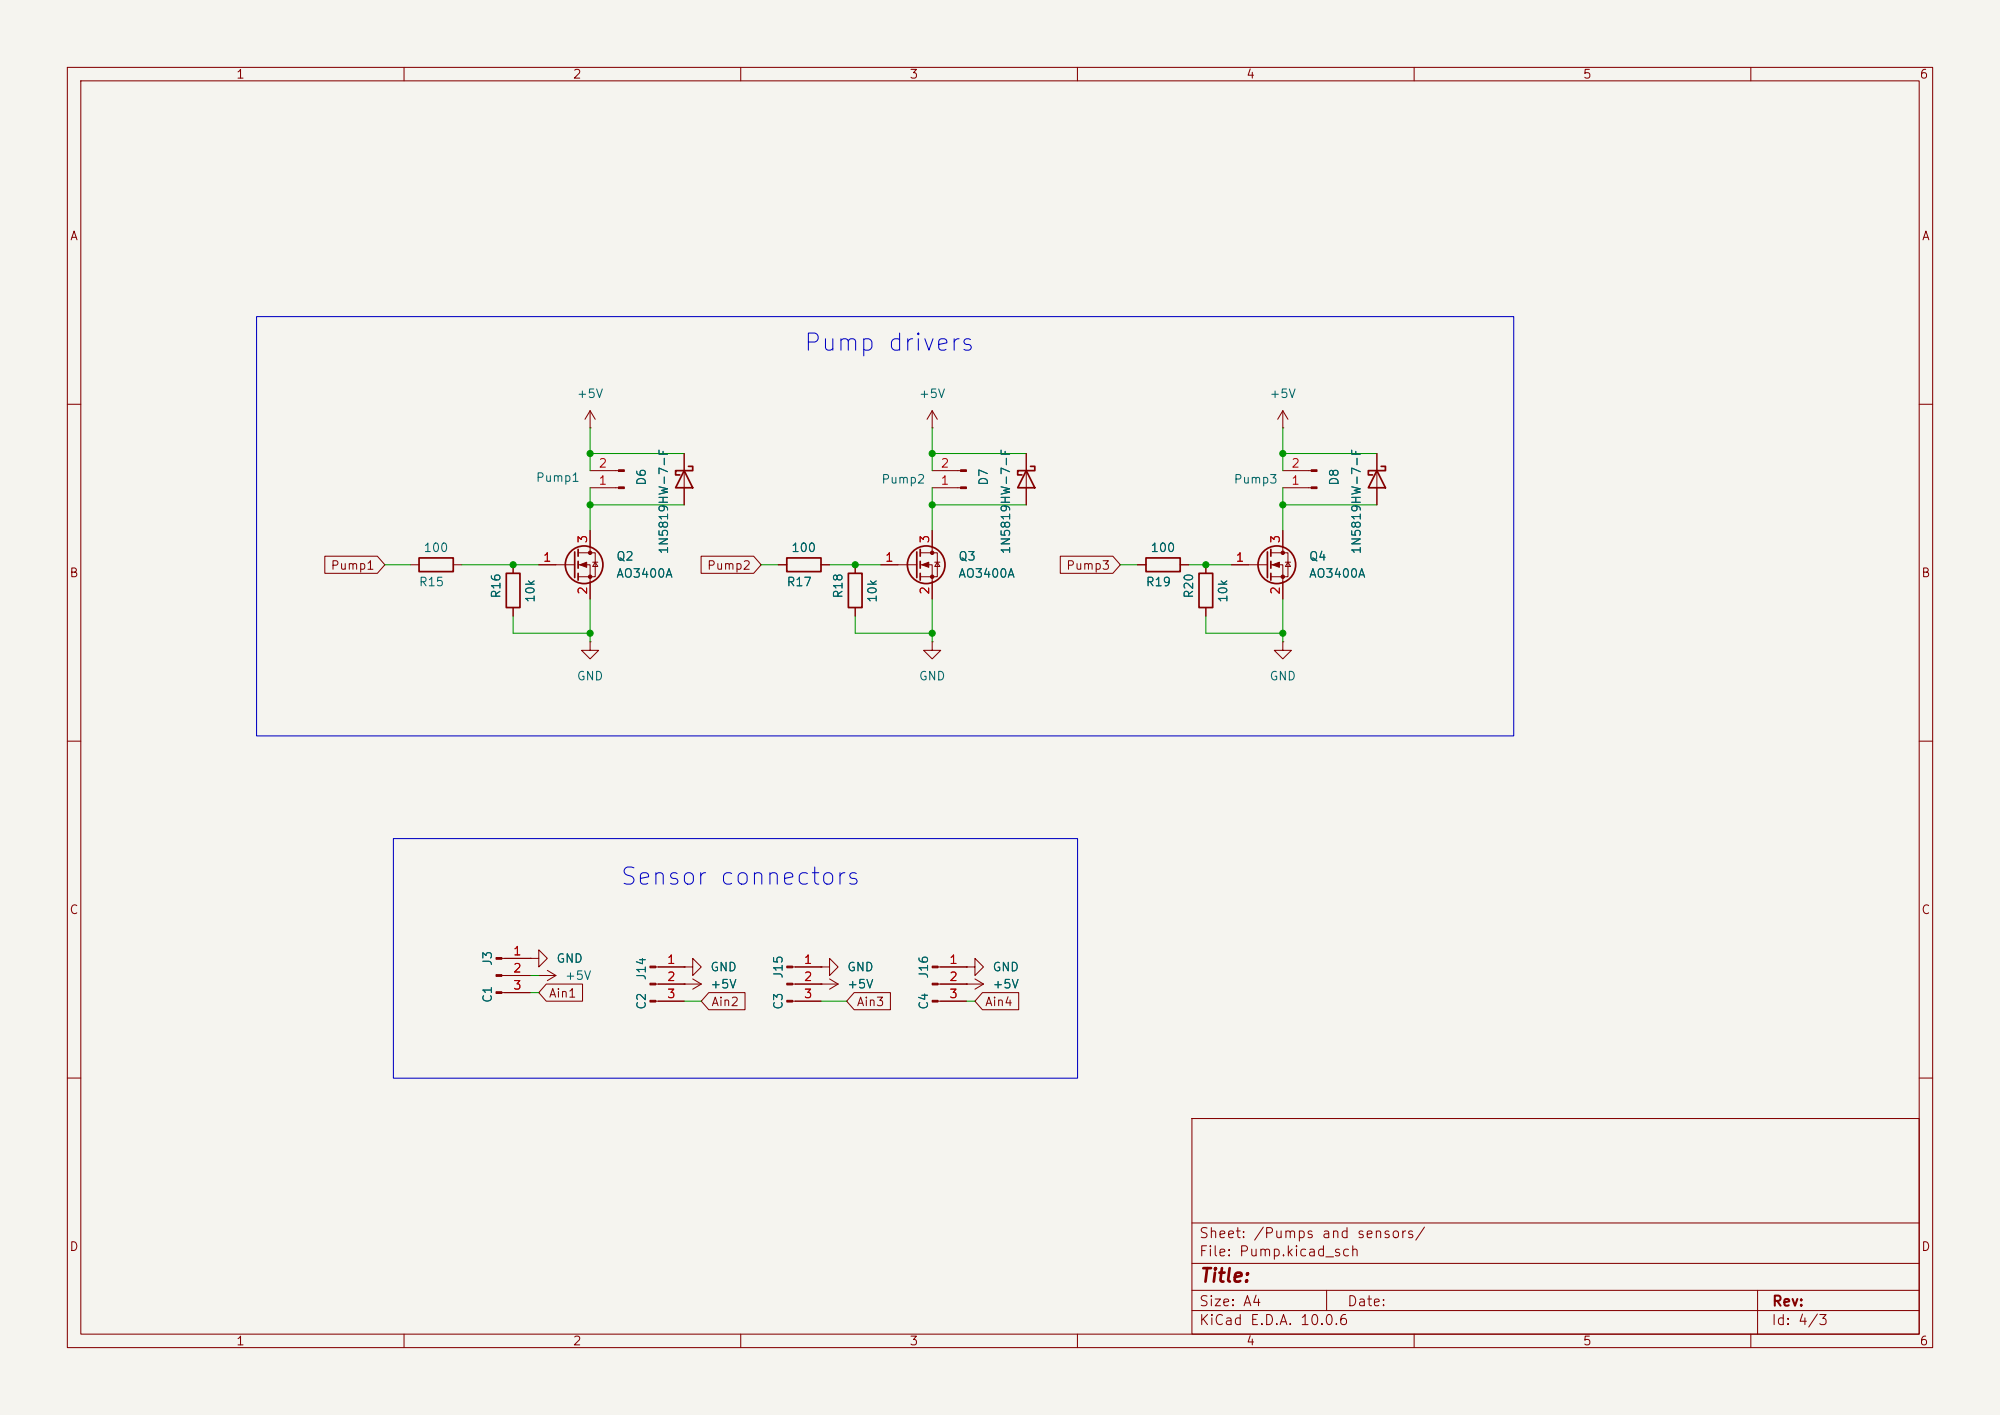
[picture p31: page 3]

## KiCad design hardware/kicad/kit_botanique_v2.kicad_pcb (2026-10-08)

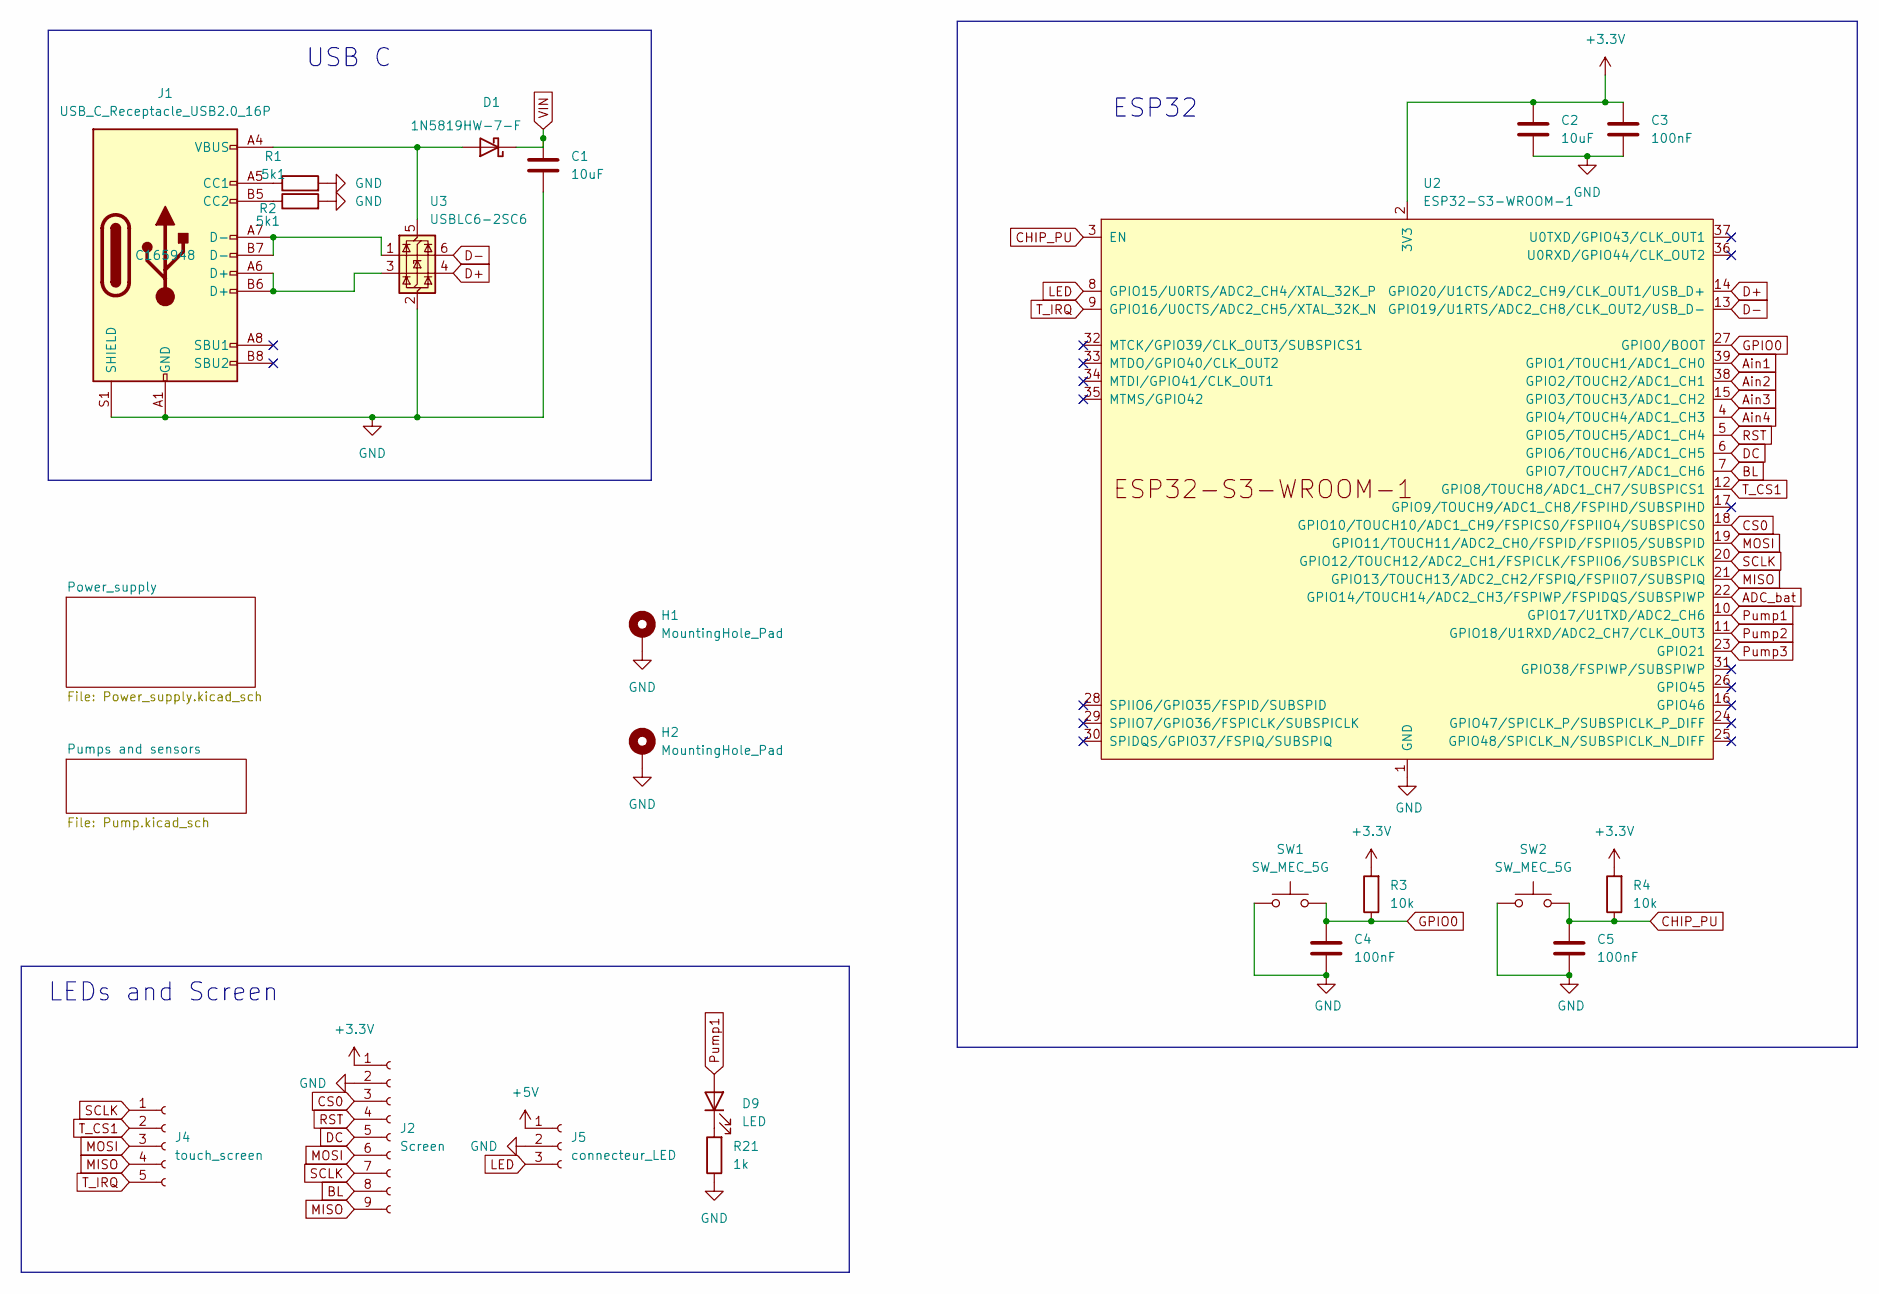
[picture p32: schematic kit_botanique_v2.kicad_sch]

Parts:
C1, C2: 10uF; C_0805_2012Metric_Pad1.18x1.45mm_HandSolder
C3, C4, C5: 100nF; C_0805_2012Metric_Pad1.18x1.45mm_HandSolder
D1: 1N5819HW-7-F; LED_0805_2012Metric_Pad1.15x1.40mm_HandSolder
D9: LED; LED_0805_2012Metric_Pad1.15x1.40mm_HandSolder
H1, H2: MountingHole_Pad; MountingHole_2.7mm_M2.5_ISO7380_Pad
J1: USB_C_Receptacle_USB2.0_16P; USB_C_Receptacle_HRO_TYPE-C-31-M-12; LCSC C165948
J2: Screen; JST_PH_B9B-PH-K_1x09_P2.00mm_Vertical
J4: touch_screen; JST_PH_B5B-PH-K_1x05_P2.00mm_Vertical
J5: connecteur_LED; JST_PH_B3B-PH-K_1x03_P2.00mm_Vertical
R1, R2: 5k1; R_0805_2012Metric_Pad1.20x1.40mm_HandSolder
R3, R4: 10k; R_0805_2012Metric_Pad1.20x1.40mm_HandSolder
R21: 1k; R_0805_2012Metric_Pad1.20x1.40mm_HandSolder
SW1, SW2: SW_MEC_5G; bouton_smd_kit_botanique
U2: ESP32-S3-WROOM-1; ESP32-S3-WROOM-1_homemade; LCSC C2913199
U3: USBLC6-2SC6; SOT-23-6

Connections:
+3.3V: C2.1, C3.1, J2.1, R3.2, R4.2, U2.2 (3V3); also elsewhere on the board
+5V: J5.1; also elsewhere on the board
ADC_bat: U2.22 (GPIO14/TOUCH14/ADC2_CH3/FSPIWP/FSPIDQS/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); also elsewhere on the board
Ain1: U2.39 (GPIO1/TOUCH1/ADC1_CH0); also elsewhere on the board
Ain2: U2.38 (GPIO2/TOUCH2/ADC1_CH1); also elsewhere on the board
Ain3: U2.15 (GPIO3/TOUCH3/ADC1_CH2); also elsewhere on the board
Ain4: U2.4 (GPIO4/TOUCH4/ADC1_CH3); also elsewhere on the board
BL: J2.8, U2.7 (GPIO7/TOUCH7/ADC1_CH6)
CHIP_PU: C5.1, R4.1, SW2.3 (B), SW2.4 (B), U2.3 (EN)
CS0: J2.3, U2.18 (GPIO10/TOUCH10/ADC1_CH9/FSPICS0/FSPIIO4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)
D+: U2.14 (GPIO20/U1CTS/ADC2_CH9/CLK_OUT1/USB_D+), U3.4 (I/O2)
D-: U2.13 (GPIO19/U1RTS/ADC2_CH8/CLK_OUT2/USB_D-), U3.6 (I/O1)
DC: J2.5, U2.6 (GPIO6/TOUCH6/ADC1_CH5)
GND: C1.2, C2.2, C3.2, C4.2, C5.2, H1.1, H2.1, J1.A1 (GND), J1.A12 (GND), J1.B1 (GND), J1.B12 (GND), J1.S1 (SHIELD), J2.2, J5.2, R1.2, R2.2, R21.1, SW1.1 (A), SW1.2 (A), SW2.1 (A), SW2.2 (A), U2.1 (GND), U2.40 (GND), U2.41 (GND), U3.2 (GND); also elsewhere on the board
GPIO0: C4.1, R3.1, SW1.3 (B), SW1.4 (B), U2.27 (GPIO0/BOOT)
LED: J5.3, U2.8 (GPIO15/U0RTS/ADC2_CH4/XTAL_32K_P)
MISO: J2.9, J4.4, U2.21 (GPIO13/TOUCH13/ADC2_CH2/FSPIQ/FSPIIO7/S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)
MOSI: J2.6, J4.3, U2.19 (GPIO11/TOUCH11/ADC2_CH0/FSPID/FSPIIO5/S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)
unnamed: D1.2 (A), J1.A4 (VBUS), J1.A9 (VBUS), J1.B4 (VBUS), J1.B9 (VBUS), U3.5 (VBUS)
unnamed: D9.1 (K), R21.2
unnamed: J1.A5 (CC1), R1.1
unnamed: J1.B5 (CC2), R2.1
unnamed: J1.A6 (D+), J1.B6 (D+), U3.3 (I/O2)
unnamed: J1.A7 (D-), J1.B7 (D-), U3.1 (I/O1)
Pump1: D9.2 (A), U2.10 (GPIO17/U1TXD/ADC2_CH6); also elsewhere on the board
Pump2: U2.11 (GPIO18/U1RXD/ADC2_CH7/CLK_OUT3); also elsewhere on the board
Pump3: U2.23 (GPIO21); also elsewhere on the board
RST: J2.4, U2.5 (GPIO5/TOUCH5/ADC1_CH4)
SCLK: J2.7, J4.1, U2.20 (GPIO12/TOUCH12/ADC2_CH1/FSPICLK/FSPIIO6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)
T_CS1: J4.2, U2.12 (GPIO8/TOUCH8/ADC1_CH7/SUBSPICS1)
T_IRQ: J4.5, U2.9 (GPIO16/U0CTS/ADC2_CH5/XTAL_32K_N)
VIN: C1.1, D1.1 (K); also elsewhere on the board

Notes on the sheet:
ESP32
USB C
LEDs and Screen

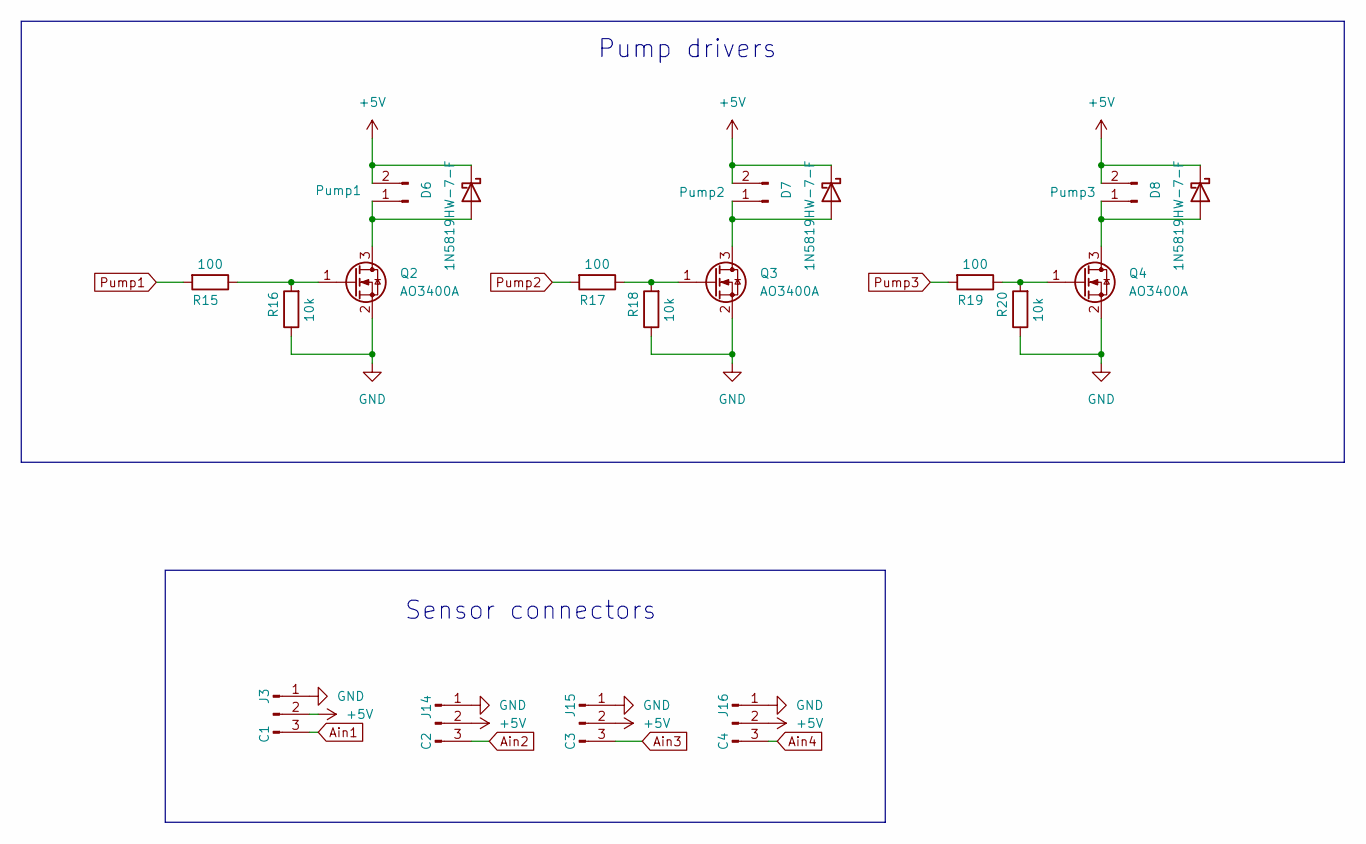
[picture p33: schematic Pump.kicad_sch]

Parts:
D6, D7, D8: 1N5819HW-7-F; LED_0805_2012Metric_Pad1.15x1.40mm_HandSolder
J3: C1; PinSocket_1x03_P2.54mm_Vertical
J11: Pump1; JST_PH_B2B-PH-K_1x02_P2.00mm_Vertical
J12: Pump2; JST_PH_B2B-PH-K_1x02_P2.00mm_Vertical
J13: Pump3; JST_PH_B2B-PH-K_1x02_P2.00mm_Vertical
J14: C2; PinSocket_1x03_P2.54mm_Vertical
J15: C3; PinSocket_1x03_P2.54mm_Vertical
J16: C4; PinSocket_1x03_P2.54mm_Vertical
Q2, Q3, Q4: AO3400A; SOT-23_Handsoldering
R15, R17, R19: 100; R_0805_2012Metric_Pad1.20x1.40mm_HandSolder
R16, R18, R20: 10k; R_0805_2012Metric_Pad1.20x1.40mm_HandSolder

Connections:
+5V: D6.1 (K), D7.1 (K), D8.1 (K), J3.2, J11.2, J12.2, J13.2, J14.2, J15.2, J16.2; also elsewhere on the board
Ain1: J3.3; also elsewhere on the board
Ain2: J14.3; also elsewhere on the board
Ain3: J15.3; also elsewhere on the board
Ain4: J16.3; also elsewhere on the board
GND: J3.1, J14.1, J15.1, J16.1, Q2.2 (S), Q3.2 (S), Q4.2 (S), R16.1, R18.1, R20.1; also elsewhere on the board
unnamed: D6.2 (A), J11.1, Q2.3 (D)
unnamed: D7.2 (A), J12.1, Q3.3 (D)
unnamed: D8.2 (A), J13.1, Q4.3 (D)
unnamed: Q2.1 (G), R15.1, R16.2
unnamed: Q3.1 (G), R17.1, R18.2
unnamed: Q4.1 (G), R19.1, R20.2
Pump1: R15.2; also elsewhere on the board
Pump2: R17.2; also elsewhere on the board
Pump3: R19.2; also elsewhere on the board

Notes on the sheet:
Pump drivers
Sensor connectors

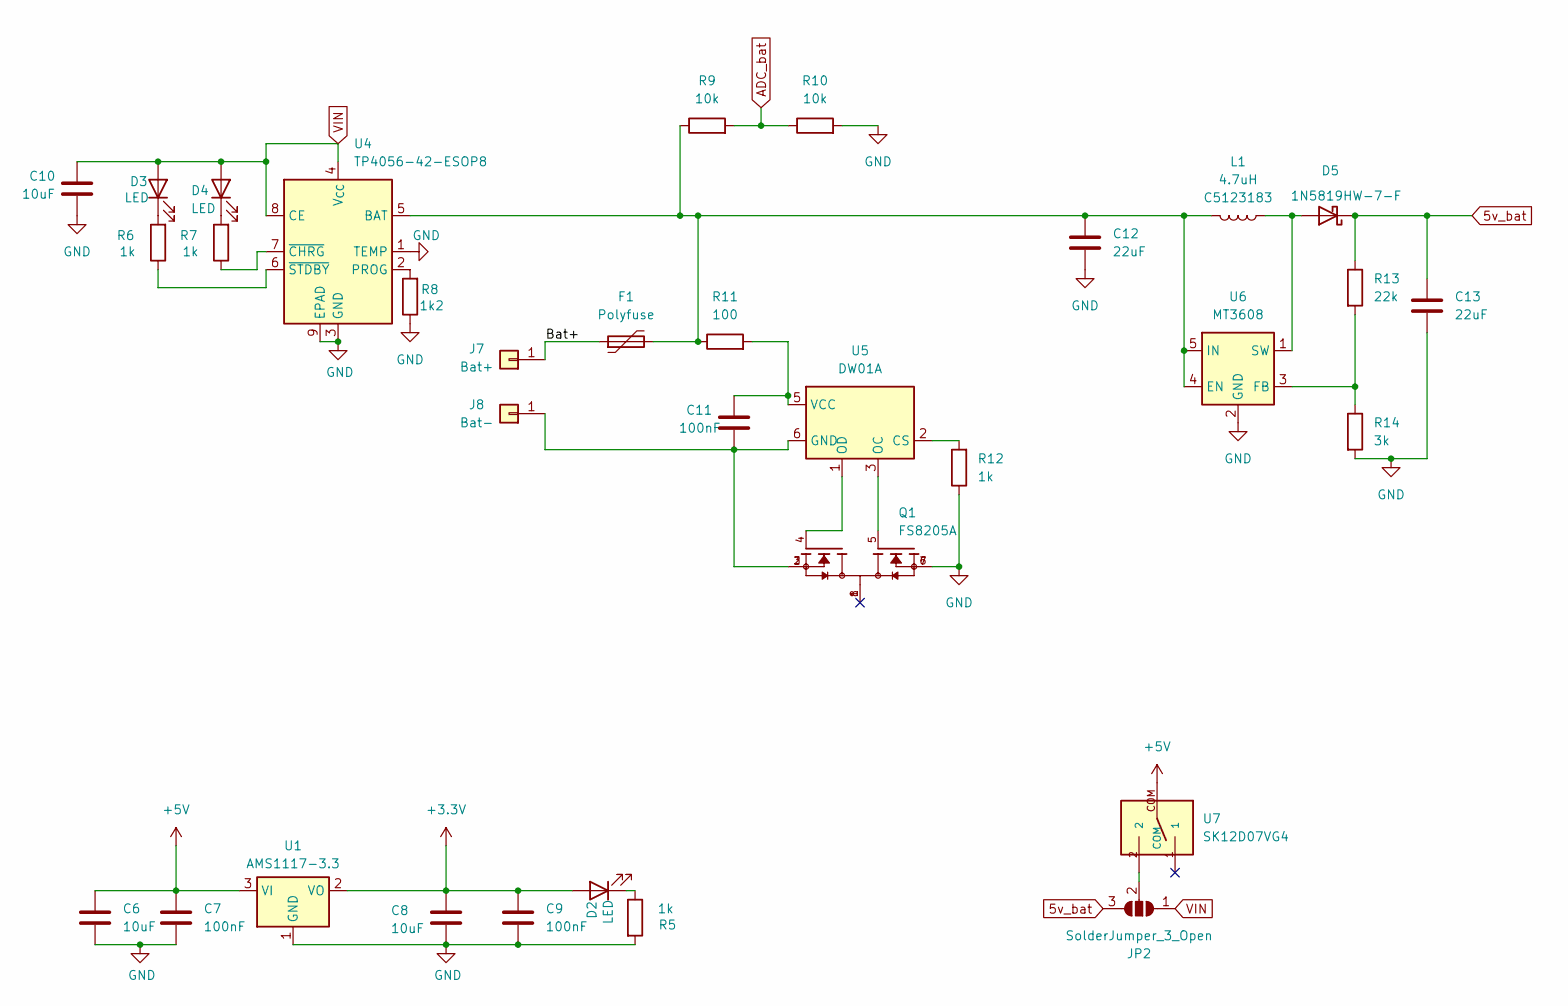
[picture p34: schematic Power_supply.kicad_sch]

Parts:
C6, C8, C10: 10uF; C_0805_2012Metric_Pad1.18x1.45mm_HandSolder
C7, C9, C11: 100nF; C_0805_2012Metric_Pad1.18x1.45mm_HandSolder
C12, C13: 22uF; C_0805_2012Metric_Pad1.18x1.45mm_HandSolder
D2, D3, D4: LED; LED_0805_2012Metric_Pad1.15x1.40mm_HandSolder
D5: 1N5819HW-7-F; LED_0805_2012Metric_Pad1.15x1.40mm_HandSolder
F1: Polyfuse; Fuse_1206_3216Metric_Pad1.42x1.75mm_HandSolder
J7: Bat+; SolderWire-1sqmm_1x01_D1.4mm_OD3.9mm
J8: Bat-; SolderWire-1sqmm_1x01_D1.4mm_OD3.9mm
JP2: SolderJumper_3_Open; SolderJumper-3_P2.0mm_Open_TrianglePad1.0x1.5mm_NumberLabels
L1: 4.7uH; inductor_48100SC; LCSC C5123183
Q1: FS8205A; SOP65P640X120-8N; PARTREV 1.7
R5, R6, R7, R12: 1k; R_0805_2012Metric_Pad1.20x1.40mm_HandSolder
R8: 1k2; R_0805_2012Metric_Pad1.20x1.40mm_HandSolder
R9, R10: 10k; R_0805_2012Metric_Pad1.20x1.40mm_HandSolder
R11: 100; R_0805_2012Metric_Pad1.20x1.40mm_HandSolder
R13: 22k; R_0805_2012Metric_Pad1.20x1.40mm_HandSolder
R14: 3k; R_0805_2012Metric_Pad1.20x1.40mm_HandSolder
U1: AMS1117-3.3; SOT-223-3_TabPin2
U4: TP4056-42-ESOP8; SOIC-8-1EP_3.9x4.9mm_P1.27mm_EP2.41x3.3mm_ThermalVias; LCSC C16581
U5: DW01A; SOT-23-6; LCSC C436931
U6: MT3608; SOT-23-6; LCSC C84817
U7: SK12D07VG4

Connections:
5v_bat: C13.1, D5.1 (K), JP2.3 (B), R13.1
+3.3V: C8.1, C9.1, D2.2 (A), U1.2 (VO); also elsewhere on the board
+5V: C6.1, C7.1, U1.3 (VI), U7.COM; also elsewhere on the board
/Power_supply/Bat+: F1.1, J7.1
ADC_bat: R9.2, R10.1; also elsewhere on the board
GND: C6.2, C7.2, C8.2, C9.2, C10.2, C12.2, C13.2, Q1.6, Q1.7, R5.2, R8.1, R10.2, R12.1, R14.2, U1.1 (GND), U4.1 (TEMP), U4.3 (GND), U4.9 (EPAD), U6.2 (GND); also elsewhere on the board
unnamed: D2.1 (K), R5.1
unnamed: D3.1 (K), R6.2
unnamed: D4.1 (K), R7.2
unnamed: D5.2 (A), L1.1, U6.1 (SW)
unnamed: C11.2, J8.1, Q1.2, Q1.3, U5.6 (GND)
unnamed: JP2.2 (C), U7.2
unnamed: C12.1, F1.2, L1.2, R9.1, R11.1, U4.5 (BAT), U6.4 (EN), U6.5 (IN)
unnamed: R8.2, U4.2 (PROG)
unnamed: R7.1, U4.7 (~CHRG)
unnamed: R6.1, U4.6 (~STDBY)
unnamed: R12.2, U5.2 (CS)
unnamed: Q1.5, U5.3 (OC)
unnamed: Q1.4, U5.1 (OD)
unnamed: C11.1, R11.2, U5.5 (VCC)
unnamed: R13.2, R14.1, U6.3 (FB)
VIN: C10.1, D3.2 (A), D4.2 (A), JP2.1 (A), U4.4 (V_{CC}), U4.8 (CE); also elsewhere on the board

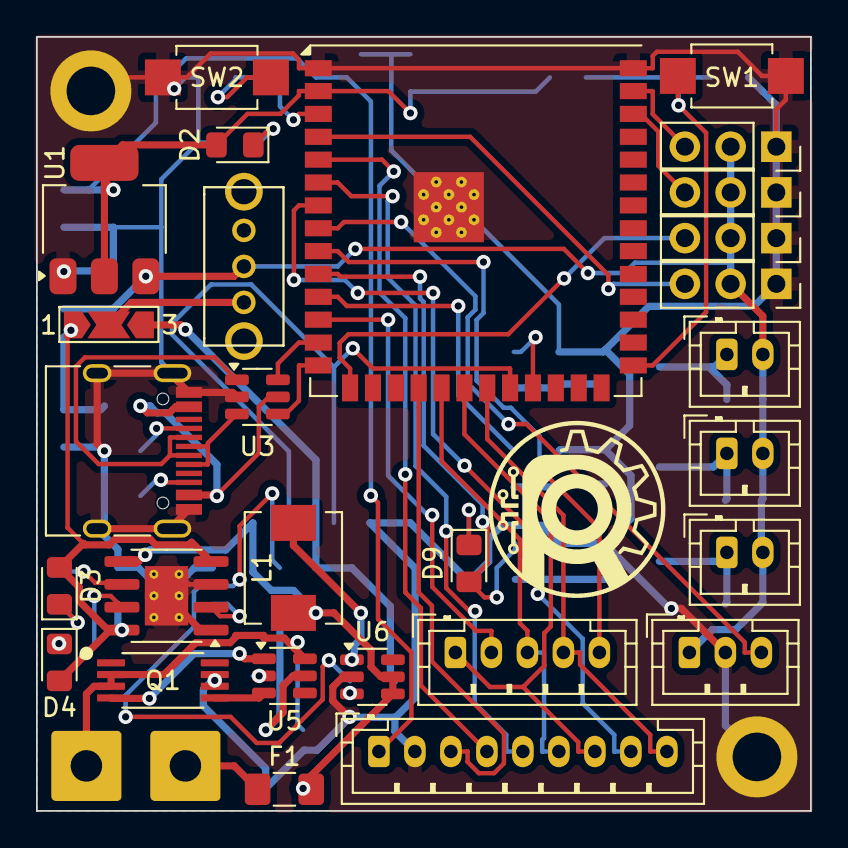
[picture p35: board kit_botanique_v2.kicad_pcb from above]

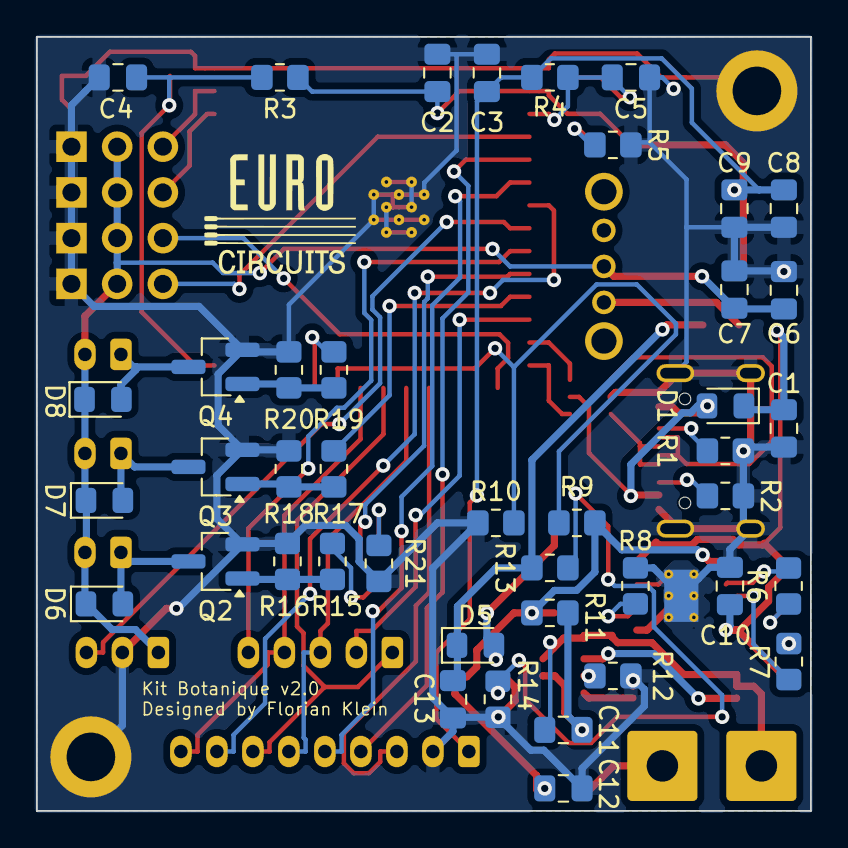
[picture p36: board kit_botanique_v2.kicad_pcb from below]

Board: 2 copper layers, 43.0 x 43.0 mm, 74 parts (42 on the bottom side), 55 nets.

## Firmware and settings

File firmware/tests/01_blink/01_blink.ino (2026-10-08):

int led_pin = 17;

void setup() {
  pinMode(led_pin, OUTPUT); // set the pin as an output
}

void loop() {
  digitalWrite(led_pin, HIGH); // turn the LED on
  delay(1000);                 // wait 1 second
  digitalWrite(led_pin, LOW);  // turn the LED off
  delay(1000);                 // wait 1 second
}

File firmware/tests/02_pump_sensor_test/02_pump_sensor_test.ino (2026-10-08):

int sensors[] = {1, 2, 3, 4};      // moisture sensors
int pumps[]   = {17, 18, 21};      // pumps

int nbSensors = 4;
int nbPumps = 3;

void setup() {
  Serial.begin(115200);

  // Sensor setup (input)
  for (int i = 0; i < nbSensors; i++) {
    pinMode(sensors[i], INPUT);
  }

  // Pump setup (output)
  for (int i = 0; i < nbPumps; i++) {
    pinMode(pumps[i], OUTPUT);
    digitalWrite(pumps[i], LOW); // pumps off at startup
  }
}

void loop() {
  Serial.println("---- Reading sensors ----");

  // Read sensors
  for (int i = 0; i < nbSensors; i++) {
    int value = analogRead(sensors[i]); // analog reading
    Serial.print("Sensor ");
    Serial.print(i);
    Serial.print(" (GPIO ");
    Serial.print(sensors[i]);
    Serial.print(") = ");
    Serial.println(value);
  }

  Serial.println("Pumps ON");

  // Turn pumps on
  for (int i = 0; i < nbPumps; i++) {
    digitalWrite(pumps[i], HIGH);
  }

  delay(3000); // 3 seconds ON

  Serial.println("Pumps OFF");

  // Turn pumps off
  for (int i = 0; i < nbPumps; i++) {
    digitalWrite(pumps[i], LOW);
  }

  delay(3000); // 3 seconds OFF
}

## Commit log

2026-10-08 Remove KiCad backups, extracted Gerbers and duplicates
    [new version-B_Cu.gbr, new version-B_Mask.gbr, new version-B_Paste.gbr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]
2026-10-08 Reorganize into docs, hardware and firmware
    [Power_supply.kicad_sch, Pump.kicad_sch, bom_v2.csv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]
2026-10-08 Update KiCad library tables
2026-10-08 Convert project to KiCad 10 format
    [Power_supply.kicad_sch, Pump.kicad_sch, kit_botanique_v2.kicad_pcb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]
2026-10-08 Add schematic PDF export
2026-10-08 Save PCB in KiCad 10 format, silkscreen v2.0
    [kit_botanique_v2.kicad_pcb]
2026-10-08 Add L1 3D model to project library
    [kit_botanique_v2.kicad_pcb]
2026-10-08 Add README and board renders
